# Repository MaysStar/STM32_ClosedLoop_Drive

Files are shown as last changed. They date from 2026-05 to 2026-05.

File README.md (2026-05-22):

Project Overview: Closed-Loop Drive System

### STM32_ClosedLoop_Drive video demonstration 

Watch video (https://www.youtube.com/watch?v=i_icI5O8THY)

*Click on the image above to go to watch the video on YouTube*

### STM32_ClosedLoop_Drive printed circuit board
Знімок екрана 2026-05-22 155104

Знімок екрана 2026-05-22 155144

Знімок екрана 2026-05-22 155350

This project is a multi-node closed-loop drive control system consisting of two main processing units: STM32F412RET and STM32F103 (Blue Pill).
1. Motion Control Node (STM32F412RET)

The core of the system, responsible for high-speed motor regulation and data management:

    Motor Control: Implements PID regulation via PWM, utilizing encoder feedback and sensor measurements for precise motion.

    Data Logging: Performs real-time logging of system parameters to an SD card (FATFS, .csv files) and via UART.

    Operating System: Runs on FreeRTOS to ensure deterministic multitasking.

    Diagnostics: Supports SEGGER debugging. All communication protocols are optimized using DMA and Interrupt (IT) functions within the OSAL layer.

2. User Interface Node (STM32F103)

A dedicated MCU for human-machine interaction:

    I/O Peripherals: Features an OLED display, physical buttons, and a potentiometer for manual speed control.

    Control: Acts as the primary input for setpoints and system monitoring.

3. Communication & Architecture

    Inter-node Communication: The MCUs communicate via a CAN bus using a custom command table where each command is assigned a specific priority.

    Software Design: The project follows a strict 3-level architecture:

        BSP (Board Support Package): Hardware abstraction and HAL-level drivers.

        OSAL (Operating System Abstraction Layer): Integration of FreeRTOS features, thread-safe DMA operations, and synchronization.

        APP (Application Layer): High-level logic for user applications and control algorithms.

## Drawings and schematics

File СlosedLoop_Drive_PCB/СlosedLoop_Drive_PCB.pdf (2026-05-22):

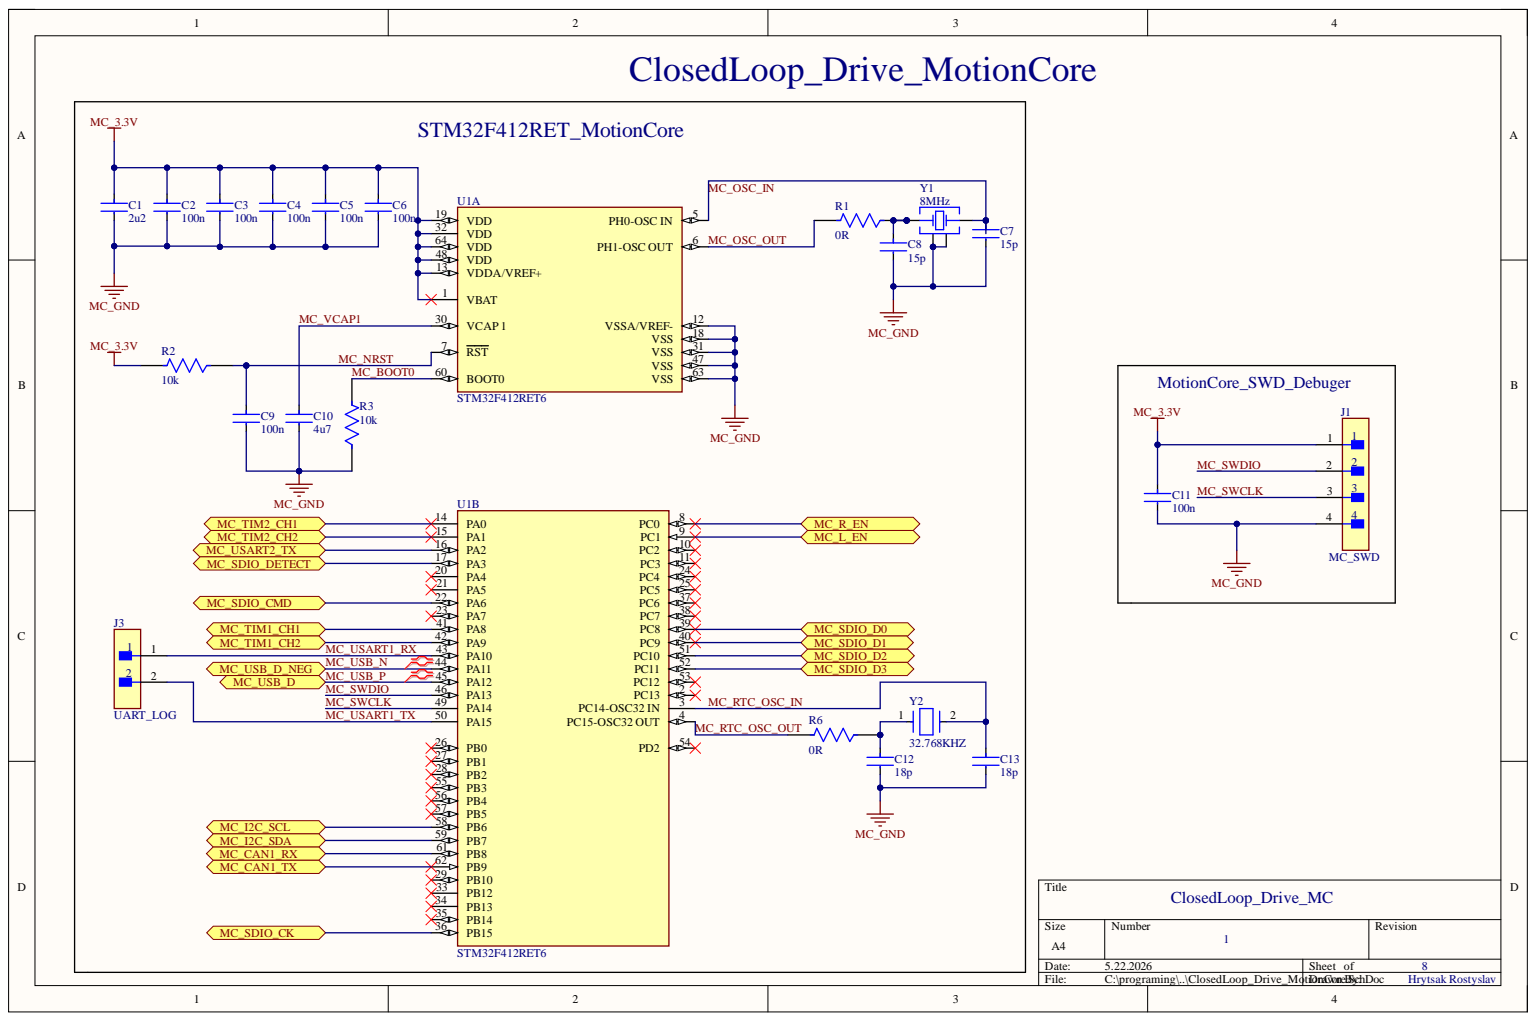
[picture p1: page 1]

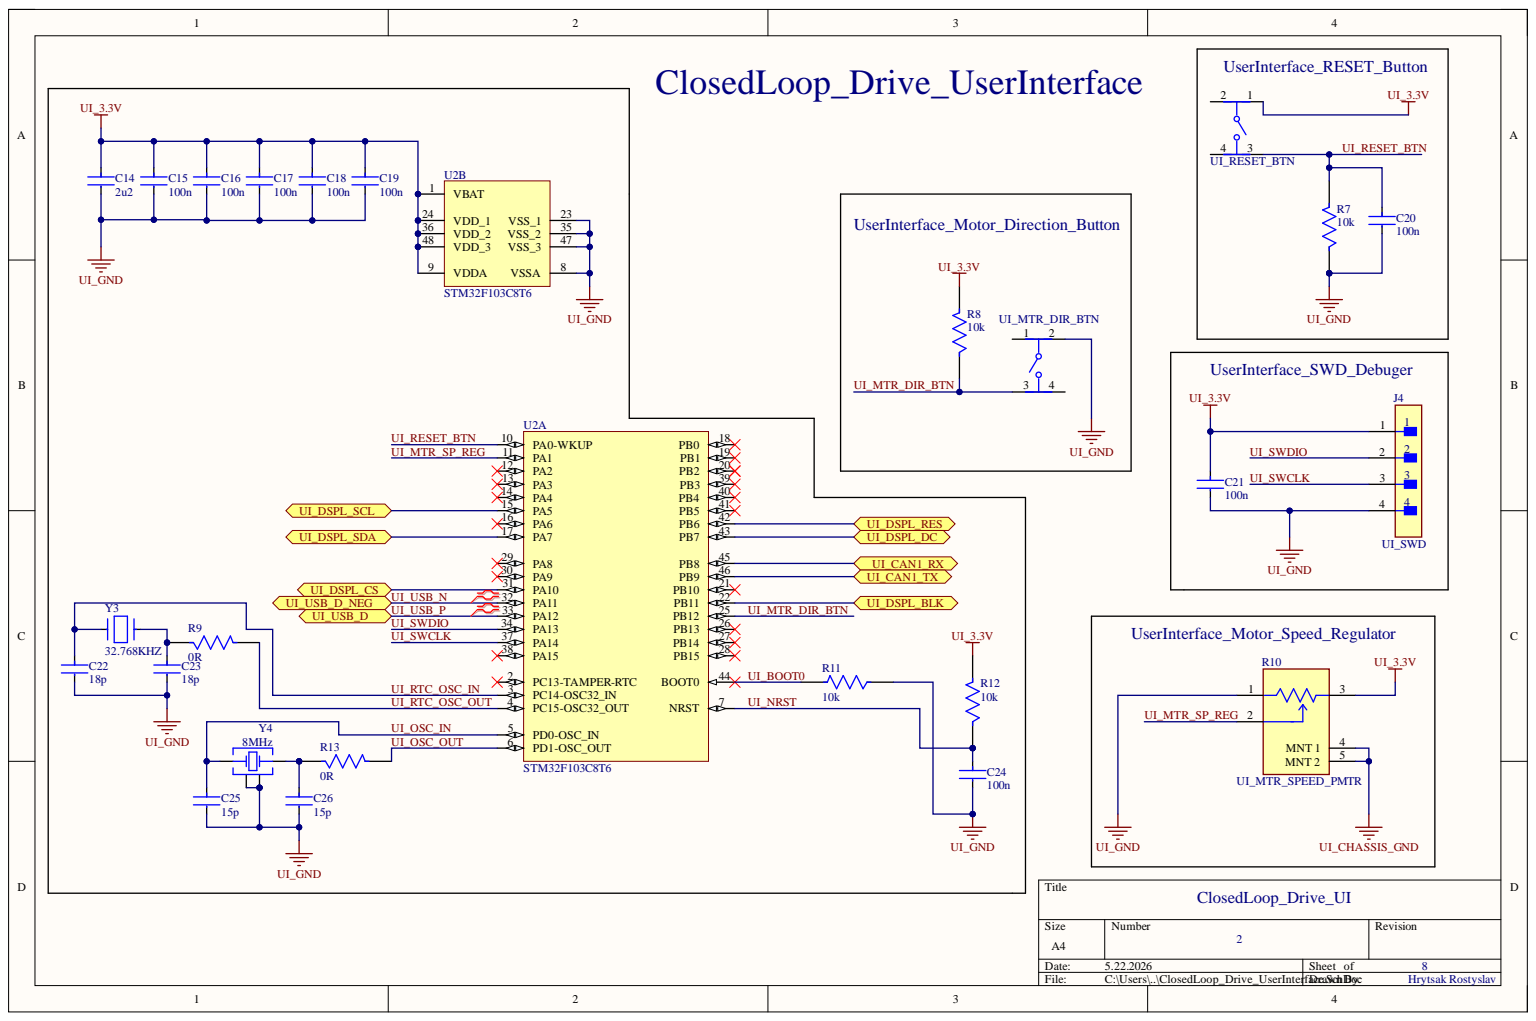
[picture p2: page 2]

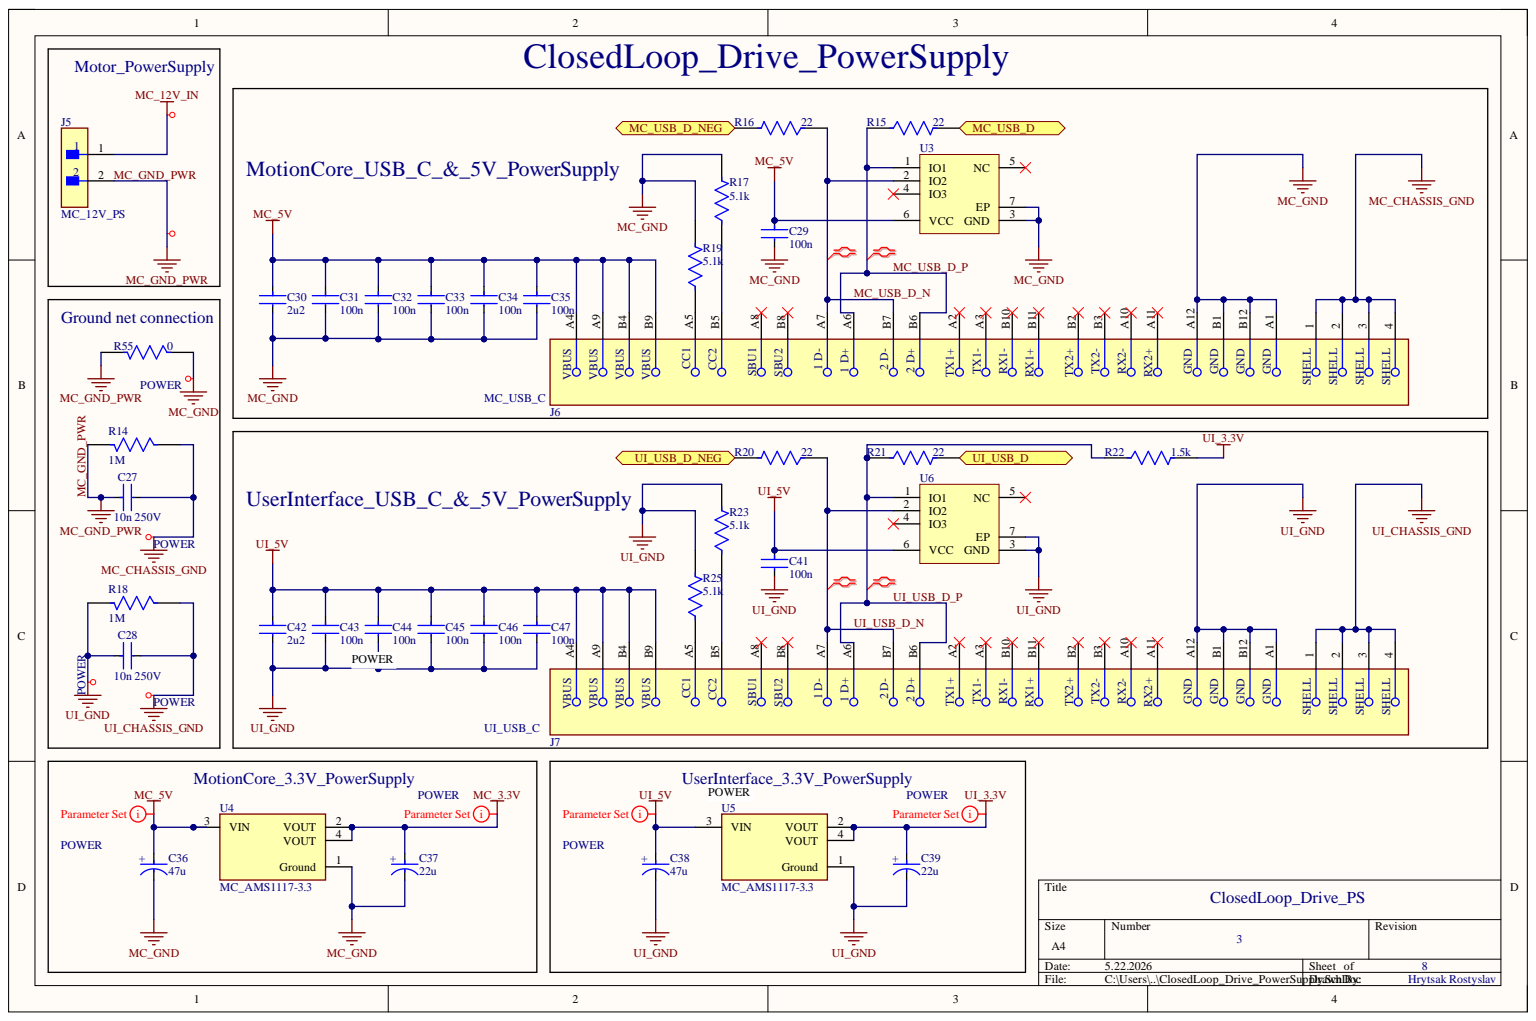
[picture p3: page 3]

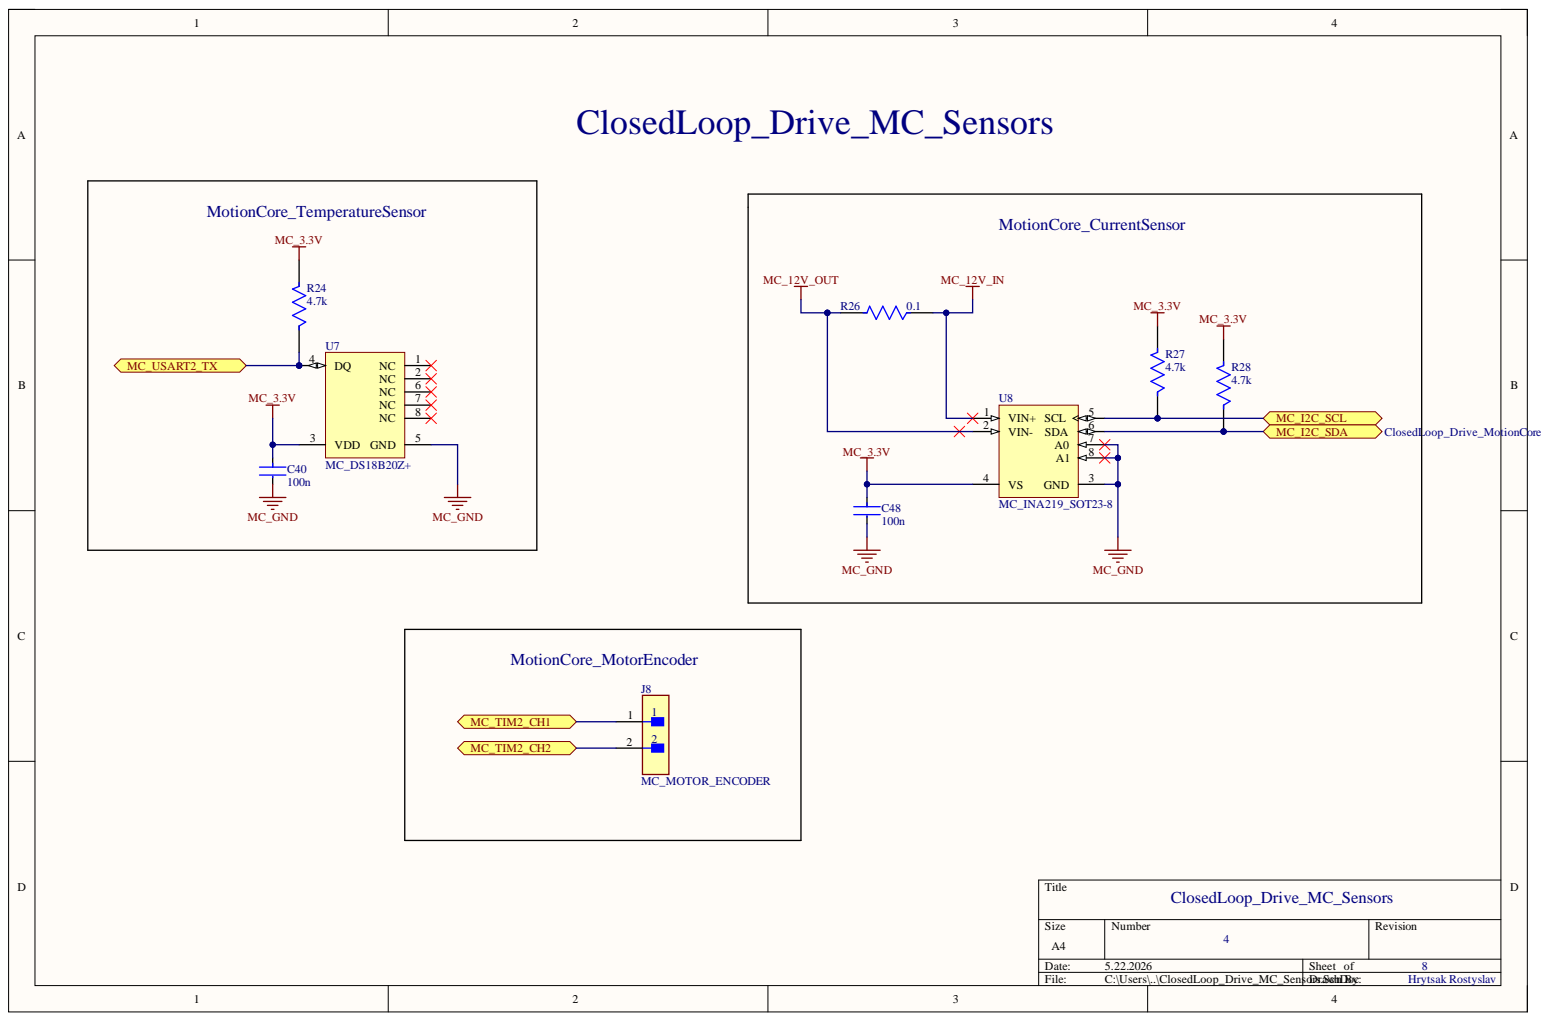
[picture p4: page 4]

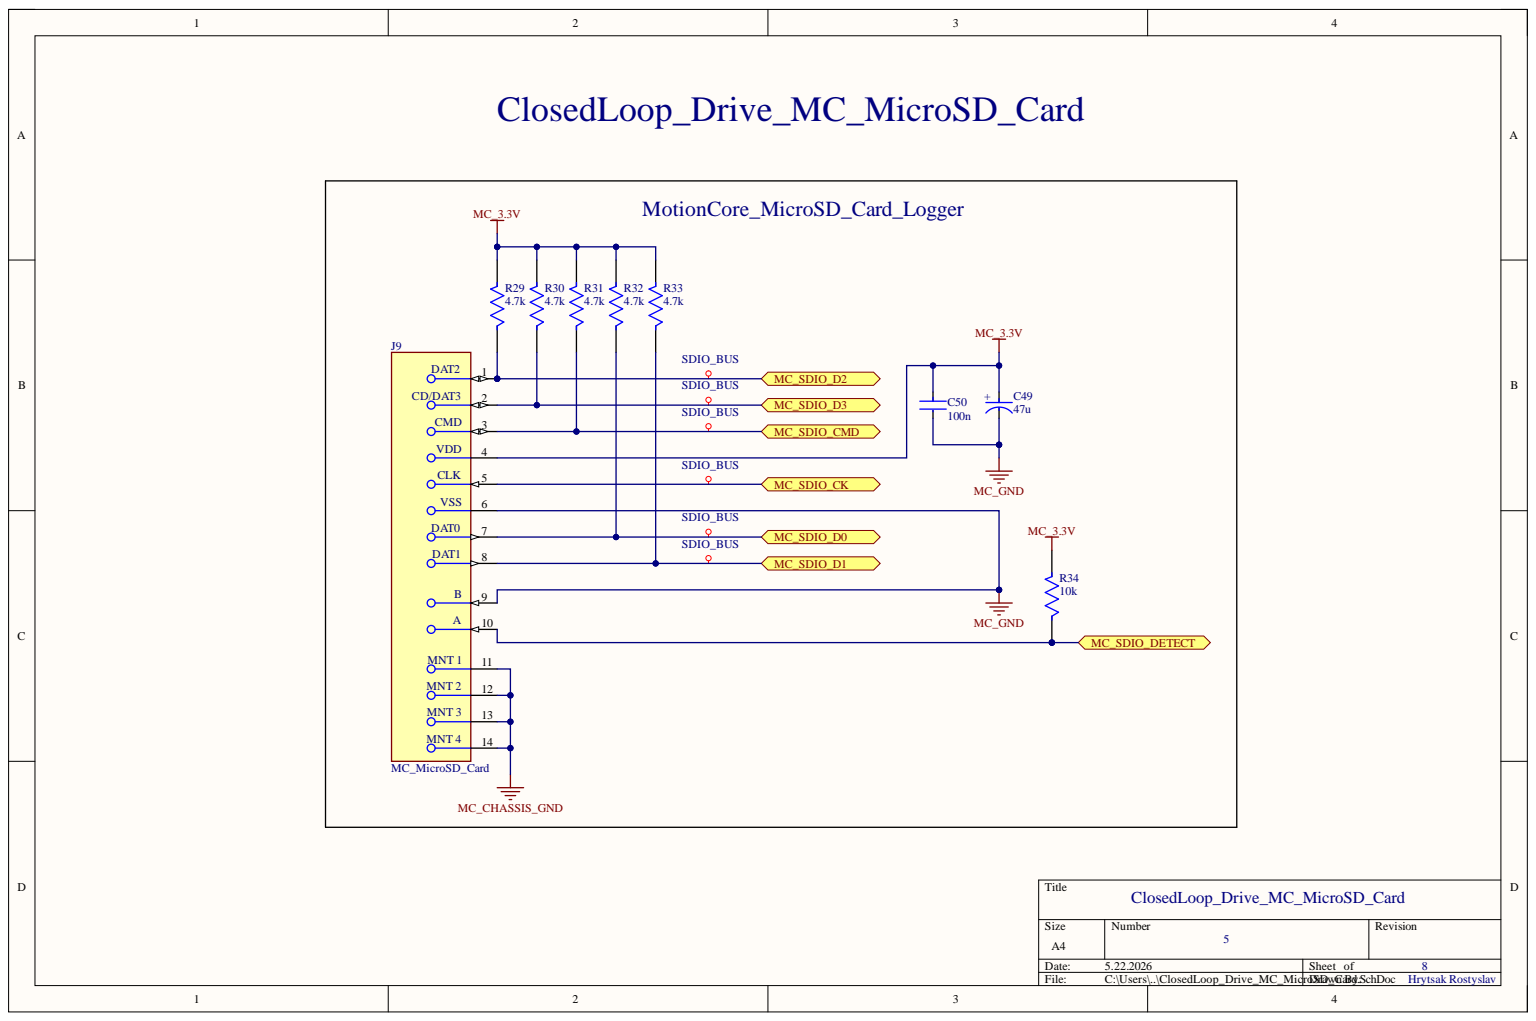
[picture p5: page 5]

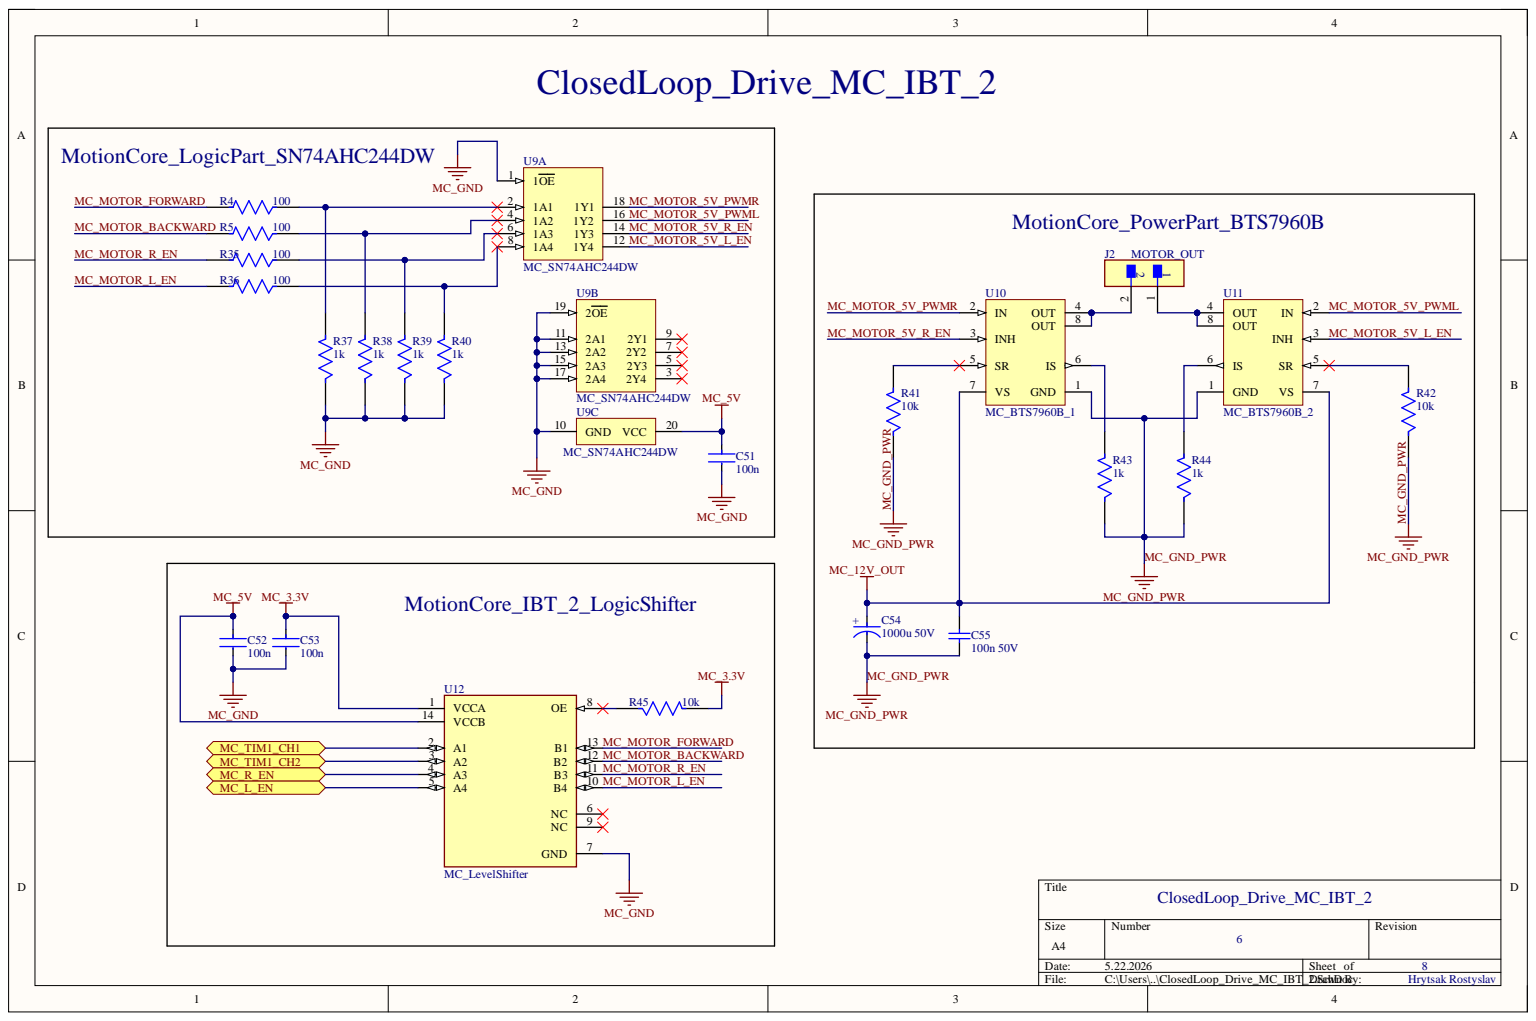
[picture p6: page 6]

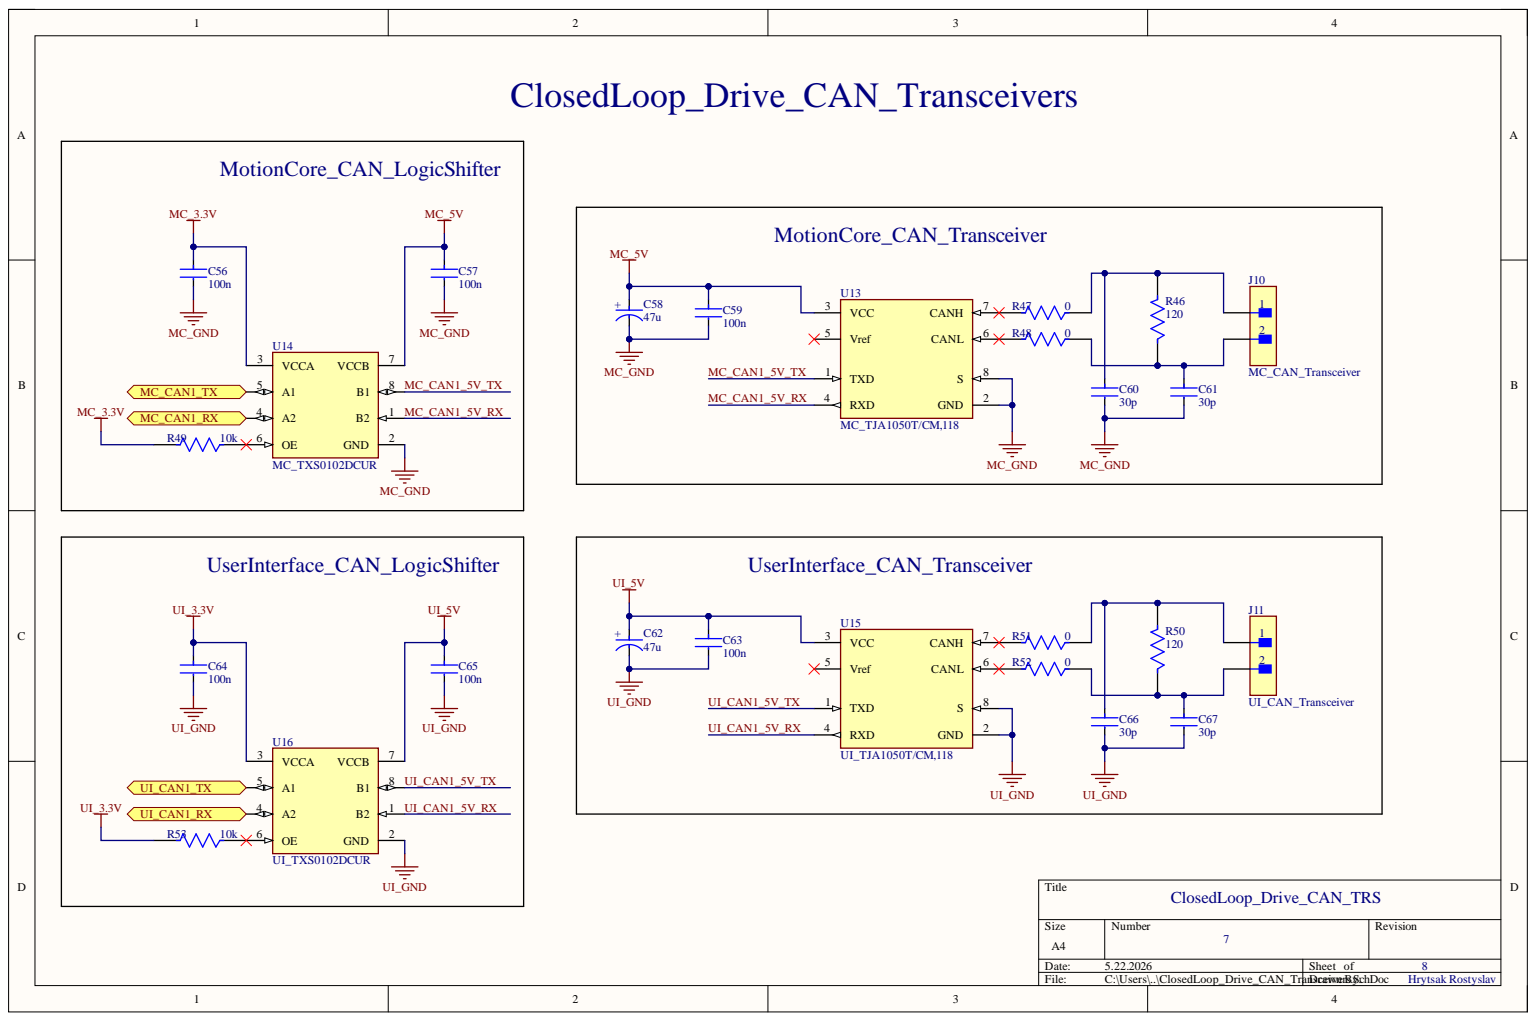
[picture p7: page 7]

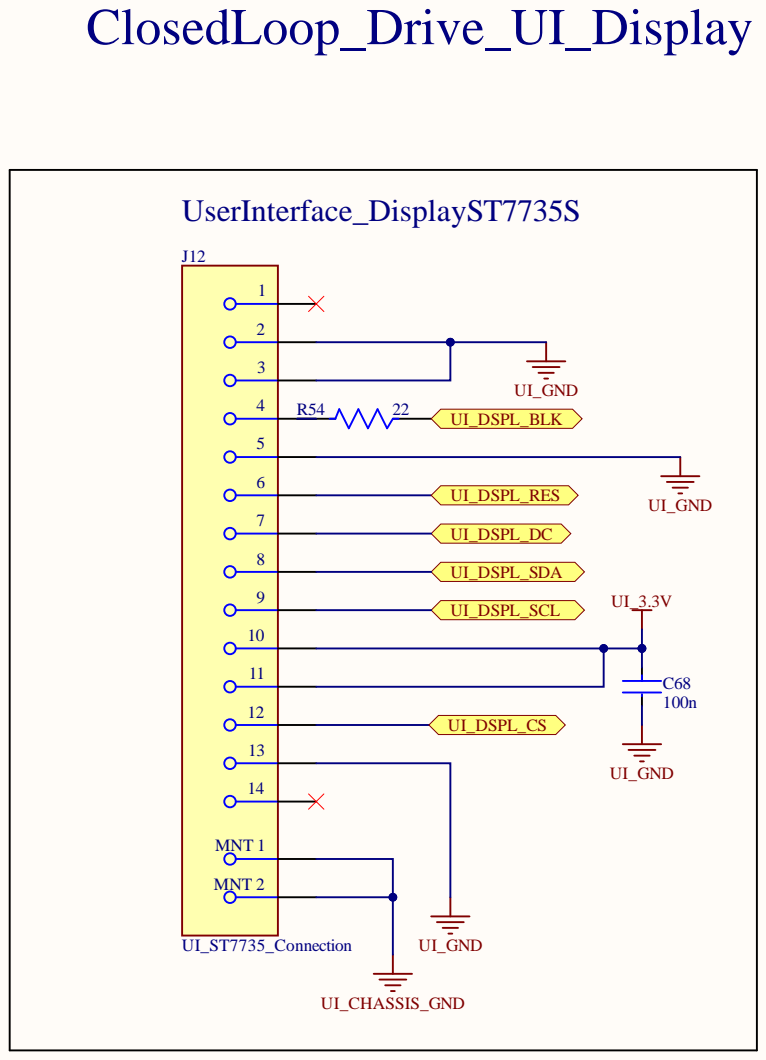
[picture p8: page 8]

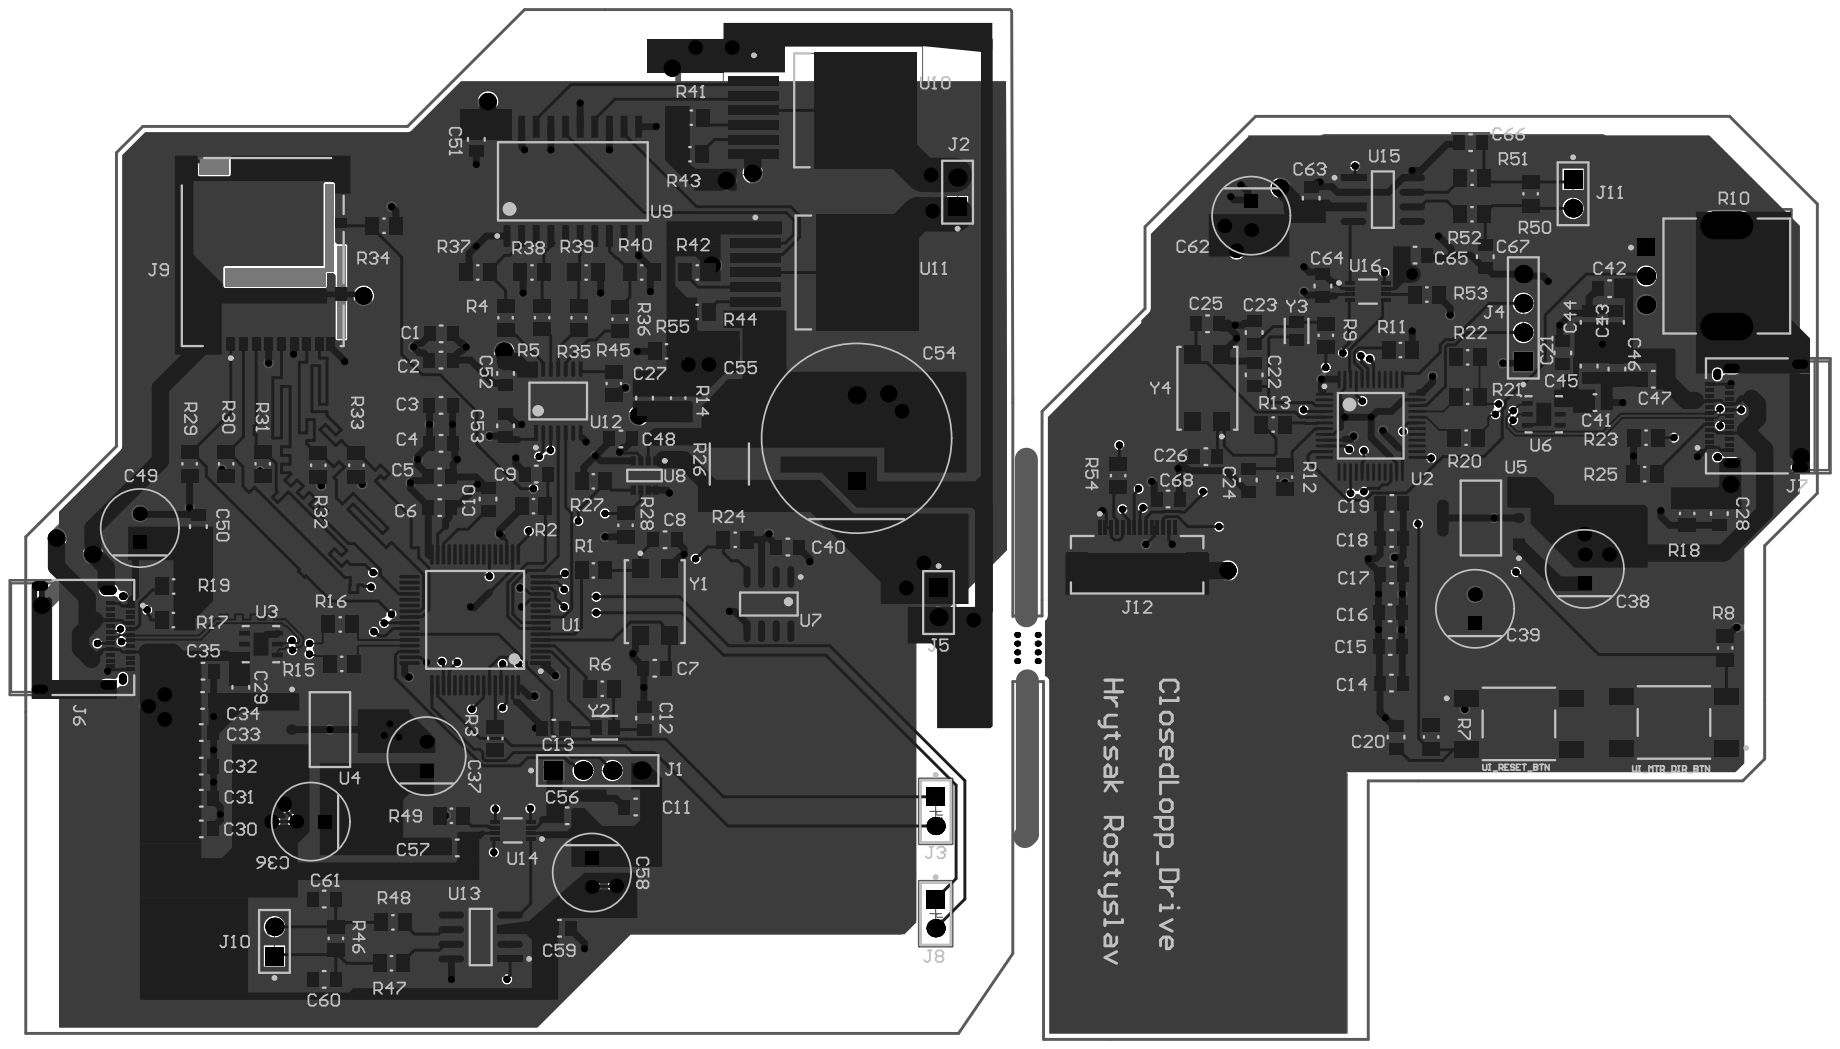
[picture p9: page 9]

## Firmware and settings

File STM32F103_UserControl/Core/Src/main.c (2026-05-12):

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
/* Includes ------------------------------------------------------------------*/
#include "main.h"

/* USER CODE BEGIN Includes */

#include "stdio.h"
#include "FreeRTOSConfig.h"
#include "FreeRTOS.h"
#include "task.h"

/* USER CODE END Includes */

ADC_HandleTypeDef hadc1;
DMA_HandleTypeDef hdma_adc1;

CAN_HandleTypeDef hcan;

IWDG_HandleTypeDef hiwdg;

RTC_HandleTypeDef hrtc;

SPI_HandleTypeDef hspi1;
DMA_HandleTypeDef hdma_spi1_tx;

void SystemClock_Config(void);
static void MX_GPIO_Init(void);
static void MX_DMA_Init(void);
static void MX_ADC1_Init(void);
static void MX_RTC_Init(void);
static void MX_SPI1_Init(void);
static void MX_IWDG_Init(void);
static void MX_CAN_Init(void);
/**
  * @brief  The application entry point.
  * @retval int
  */
int main(void)
{
  /* MCU Configuration--------------------------------------------------------*/

  /* Reset of all peripherals, Initializes the Flash interface and the Systick. */
  HAL_Init();

  /* USER CODE BEGIN Init */

  /* Enable DWT clock for proper work SEGGER SYSVIEW */
  CoreDebug->DEMCR |= CoreDebug_DEMCR_TRCENA_Msk;
  DWT->CYCCNT = 0;
  DWT->CTRL |= DWT_CTRL_CYCCNTENA_Msk;

  /* Set grouping priority manually for avoiding freeRTOS conflicts */
  NVIC_SetPriorityGrouping(0);

  /* USER CODE END Init */

  /* Configure the system clock */
  SystemClock_Config();

  /* Initialize all configured peripherals */
  MX_GPIO_Init();
  MX_DMA_Init();
  MX_ADC1_Init();
  MX_RTC_Init();
  MX_SPI1_Init();
//  MX_IWDG_Init();
  MX_CAN_Init();
  /* USER CODE BEGIN 2 */

  /* Set Hardware and start application layer */
  AppHardwareConfig_t app_hw =
  {
	.padc1 = &hadc1,
	.prtc = &hrtc,
	.piwdg = &hiwdg,
	.pspi1 = &hspi1,
	.pcan = &hcan,
  };
  APP_Main(&app_hw);

  /* USER CODE END 2 */

  /* Infinite loop */
  /* USER CODE BEGIN WHILE */
  while (1)
  {
    /* USER CODE END WHILE */

    /* USER CODE BEGIN 3 */
  }
  /* USER CODE END 3 */
}

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
/* USER CODE BEGIN 4 */

void vApplicationStackOverflowHook(void)
{
	while(1)
	{

	}
}

/* USER CODE END 4 */

/**
  * @brief  Period elapsed callback in non blocking mode
  * @note   This function is called  when TIM4 interrupt took place, inside
  * HAL_TIM_IRQHandler(). It makes a direct call to HAL_IncTick() to increment
  * a global variable "uwTick" used as application time base.
  * @param  htim : TIM handle
  * @retval None
  */
void HAL_TIM_PeriodElapsedCallback(TIM_HandleTypeDef *htim)
{
  if (htim->Instance == TIM4) {
    HAL_IncTick();
  }
}

/**
  * @brief  This function is executed in case of error occurrence.
  * @retval None
  */
void Error_Handler(void)
{
  /* USER CODE BEGIN Error_Handler_Debug */
  /* User can add his own implementation to report the HAL error return state */
  __disable_irq();
  while (1)
  {
  }
  /* USER CODE END Error_Handler_Debug */
}

#ifdef  USE_FULL_ASSERT
/**
  * @brief  Reports the name of the source file and the source line number
  *         where the assert_param error has occurred.
  * @param  file: pointer to the source file name
  * @param  line: assert_param error line source number
  * @retval None
  */
void assert_failed(uint8_t *file, uint32_t line)
{
  /* USER CODE BEGIN 6 */
  /* User can add his own implementation to report the file name and line number,
     ex: printf("Wrong parameters value: file %s on line %d\r\n", file, line) */
  /* USER CODE END 6 */
}
#endif /* USE_FULL_ASSERT */

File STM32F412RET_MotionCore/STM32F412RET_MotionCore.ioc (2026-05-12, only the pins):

Mcu.UserName=STM32F412RETx
PA0.Signal=S_TIM2_CH1_ETR
PA1.Signal=S_TIM2_CH2
PA10.Signal=USART1_RX
PA12.Signal=CAN1_TX
PA13.Signal=SYS_JTMS-SWDIO
PA14.Signal=SYS_JTCK-SWCLK
PA15.Signal=USART1_TX
PA2.Signal=USART2_TX
PA4.Signal=GPIO_Output
PA6.Signal=SDIO_CMD
PA7.Signal=GPIO_Output
PA8.Signal=S_TIM1_CH1
PA9.Signal=S_TIM1_CH2
PB15.Signal=SDIO_CK
PB6.Signal=I2C1_SCL
PB7.Signal=I2C1_SDA
PB8.Signal=CAN1_RX
PC0.Signal=GPIO_Output
PC1.Signal=GPIO_Output
PC10.Signal=SDIO_D2
PC11.Signal=SDIO_D3
PC8.Signal=SDIO_D0
PC9.Signal=SDIO_D1

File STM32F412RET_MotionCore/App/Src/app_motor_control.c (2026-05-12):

#include "app_motor_control.h"

/* private variables */
static volatile float actual_speed_percent = 0.0f;
static volatile float current_recover_pwm = 0.0f;

static float filtered_speed = 0.0f;

static PID_Controller_t PID_Controller = {0};

static TaskHandle_t motor_control_handle = NULL;
static void motor_control_task(void* pvParameters);

/* Initialize PID controller */
static void APP_MOTOR_CONTROL_PID_Controller_init(PID_Controller_t* PID_Controller)
{
	if(PID_Controller != NULL)
	{
		PID_Controller->Kp = 4.0f;
		PID_Controller->Ki = 1.5f;
		PID_Controller->Kd = 0.02f;

		PID_Controller->min_result = -100.0f;
		PID_Controller->max_result = 100.0f;

		PID_Controller->prev_error = 0.0f;
		PID_Controller->prev_measurement = 0.0f;

		PID_Controller->proportional = 0.0f;
		PID_Controller->integrator = 0.0f;
		PID_Controller->differentiator = 0.0f;

		/* 10 * dt, dt = 50ms tau = 500ms */
		PID_Controller->tau = 0.05f;

		PID_Controller->out = 0.0f;
	}
}
/* Fuction which control the speed of the motors speed, using Proportional Integration Differential
    u(t) = Kp * e(t) + Ki * iteg(e(t)dt) + Kd * de(t) / dt
*/
static float APP_MOTOR_CONTROL_PID_Update(PID_Controller_t* PID_controler, float measurement, float setpoint)
{
	/* Calculate error */
	float curr_error = setpoint - measurement;

	float dt_f = 0.05f;

	if(setpoint < 5.0)
	{
		return 0.0f;
	}

	/* Proportional */
	PID_controler->proportional = PID_controler->Kp * curr_error;

	/* Integrator Trapezoidal Rule */
	PID_controler->integrator = PID_controler->integrator + 0.5f * PID_controler->Ki * (PID_controler->prev_error + curr_error) * dt_f;

	/* Band-Limited Derivative */
	float diff_num = measurement - PID_controler->prev_measurement;
	PID_controler->differentiator =   (2.0f * PID_controler->Kd * diff_num
	                      - (2.0f * PID_controler->tau - dt_f) * PID_controler->differentiator)
	                      / (2.0f * PID_controler->tau + dt_f);
	/* Set prev measurement */
	PID_controler->prev_error = curr_error;
	PID_controler->prev_measurement = measurement;

	/* Calculate output */
	float out_raw = PID_controler->proportional + PID_controler->integrator - PID_controler->differentiator;

	/* Anti-windup back-calculation */
	float out_clamped = CLAMP(out_raw, PID_controler->min_result, PID_controler->max_result);
	PID_controler->integrator += (out_clamped - out_raw) * 0.1f;

	/* Assign final output */
	PID_controler->out = out_clamped;

	return PID_controler->out;
}

/* Initialize timer1 PWM and check errors */
void APP_MOTOR_CONTROL_init(TIM_HandleTypeDef* ptim1, TIM_HandleTypeDef* ptim2)
{
	APP_STATE_Update_Error_BeforeRTOSStart(ERR_TIM_PWM, ERR_ACTIVE);

	for(uint32_t i = 0; i < 3; ++i)
	{
		if(BSP_MOTOR_CONTROL_Init(ptim1, ptim2) == DRV_OK)
		{
			APP_STATE_Update_Error_BeforeRTOSStart(ERR_TIM_PWM, ERR_NOT_ACTIVE);
			break;
		}
	}

	/* Initialize PID control system */
	APP_MOTOR_CONTROL_PID_Controller_init(&PID_Controller);

	xTaskCreate(motor_control_task, "motor_control_task", 1024, NULL, 3, &motor_control_handle);
	configASSERT(motor_control_handle != NULL);
}

static float pid_pwm_percent;
static float encoder_delta;

/* Main task for Motor Control using State machine, PID and PWM */
static void motor_control_task(void* pvParameters)
{
	TickType_t xLastWakeTime;
	const TickType_t xFrequency = 50;

	APP_STATE_Set_Motor_TargetSpeed(10.0f);

	// Initialize the xLastWakeTime variable with the current time.
	xLastWakeTime = xTaskGetTickCount();

	while(1)
	{
		GlobalData_t global_state = APP_STATE_Get_Data();

		/* Start condition */
		if((global_state.motor_state == MOTOR_STOP) &&
		   (global_state.target_motor_speed != 0))
		{
			PID_Controller.integrator = 0.0f;
			PID_Controller.differentiator = 0.0f;
			PID_Controller.prev_error = 0.0f;
			PID_Controller.prev_measurement = actual_speed_percent;

			APP_STATE_Set_Motor_State(MOTOR_RUN);
		}

		encoder_delta = (float)OSAL_MOTOR_CONTROL_GetEncoderDifference();
		encoder_delta = (encoder_delta >= 0) ? encoder_delta : (-encoder_delta);

		/* Calculate speed in percent according to motor max speed */
		// encoder_dt = 50.
		actual_speed_percent = ((encoder_delta * 100) / APP_MOTOR_CONTROL_MAX_ENCODER_VAL_P50MS);

		APP_STATE_Set_Motor_ActualSpeed(actual_speed_percent);

		// low-pass filter
		filtered_speed = SPEED_FILTER_ALPHA * actual_speed_percent
		               + (1.0f - SPEED_FILTER_ALPHA) * filtered_speed;

		/* Target PWM value from PID control system */
		pid_pwm_percent = APP_MOTOR_CONTROL_PID_Update(&PID_Controller, filtered_speed, global_state.target_motor_speed);

		switch(global_state.motor_state)
		{
			case MOTOR_RUN:
			{
				if(OSAL_MOTOR_ChangePWM_State(pid_pwm_percent, global_state.motor_direction) != DRV_OK)
				{
					APP_STATE_Update_Error(ERR_TIM_PWM, ERR_ACTIVE);
				}
				else
				{
					APP_STATE_Update_Error(ERR_TIM_PWM, ERR_NOT_ACTIVE);
				}

				break;
			}
			case MOTOR_STOP:
			{
				actual_speed_percent = 0.0f;
				if(OSAL_MOTOR_ChangePWM_State(actual_speed_percent, MOTOR_ORDINARY_STOP) != DRV_OK)
				{
					APP_STATE_Update_Error(ERR_TIM_PWM, ERR_ACTIVE);
				}
				else
				{
					APP_STATE_Update_Error(ERR_TIM_PWM, ERR_NOT_ACTIVE);
				}
				break;
			}
			case MOTOR_RECOVER:
			{
				/* Increase value step by step */
				current_recover_pwm += 5.0f;

				if(current_recover_pwm >= pid_pwm_percent)
				{
					/* acceleration is finish */
					current_recover_pwm = pid_pwm_percent;
					APP_STATE_Set_Motor_State(MOTOR_RUN);
				}

				if(OSAL_MOTOR_ChangePWM_State(current_recover_pwm, global_state.motor_direction) != DRV_OK)
				{
					APP_STATE_Update_Error(ERR_TIM_PWM, ERR_ACTIVE);
				}
				else
				{
					APP_STATE_Update_Error(ERR_TIM_PWM, ERR_NOT_ACTIVE);
				}

				break;
			}
			case MOTOR_FAULT_STOP:
			{
				actual_speed_percent = 0.0f;
				if(OSAL_MOTOR_ChangePWM_State(actual_speed_percent, MOTOR_EMERGENCY_STOP) != DRV_OK)
				{
					APP_STATE_Update_Error(ERR_TIM_PWM, ERR_ACTIVE);
				}
				else
				{
					APP_STATE_Update_Error(ERR_TIM_PWM, ERR_NOT_ACTIVE);
				}

				/* Start recover speed */
				current_recover_pwm = 0.0f;
				APP_STATE_Set_Motor_State(MOTOR_RECOVER);
				break;
			}
			default:
				break;
		}

		vTaskDelayUntil(&xLastWakeTime, pdMS_TO_TICKS(xFrequency));
	}
}

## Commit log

2026-03-22 first initial commit with motor control architecture
2026-03-29 Add SD card and UART logging using DMA, FatFs, and FreeRTOS
    * SDIO and FatFs was configured by manual SDIO 4-bit mode with DMA for Sd card logging and also some debug feaches like ITM, SWO, SWV was added
    * Developed SD DMA with RTOS implementation. Additionally, added a UART2 logger also with DMA and function pointer in the BSP to follow the architecture
    * Solved some bugs in diskio.c and added a mutex on the SDIO bus
    * Solved some architecture problems (added a new architecture layer called OSAL). Implemented a threadsafe function for UART DMA transmission. Also created a Mutex and improved the DMA callback for SDIO in diskio.c
    [STM32F4_MotionCore Debug.cfg]
2026-03-30 Implemented SEGGER SYSVIEW to visualize system execution. The traces can be generated using .SVdat files
2026-03-30 Developed better structure for SEGGER's files
    * Implemented SEGGER SYSVIEW to visualize system execution. The traces can be generated using .SVdat files
    * Developed better segger's files structure
2026-04-05 Temperature, current, power and voltage sensors implementation
    * Implemented BSP and OSAL layers for DS18B20 temperature sensor. This is demo version, so the implementation may change based on real hardware testing
    * Add project overview for Closed-Loop Drive System
    Added project overview and detailed descriptions of the closed-loop drive system components, including the Motion Control Node and User Interface Node.
    * Refactored application architecture and solved some previous issues
    * Implemented INA219 driver for current, power and voltage measurements. Also added OSAL layer functions for thread-safe use. All tests passed successfully
    [STM32F4_MotionCore.ioc, app_main.c, app_sensors.c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]
2026-04-06 Fault tolerance and independent watchdog
    * Developed a new software safety system with strict state validation fo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
    [STM32F4_MotionCore.ioc, app_main.c, app_sensors.c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]
2026-04-14 Developed RTC based on LSI. Refactor OSAL: fix timeout handling issues
    [STM32F4_MotionCore.ioc, app_housekeeping.c, app_main.c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]
2026-04-14 feat: Implement TIM1 PWM (BSP, OSAL, APP layers). WIP: initial safety and user motor control implementations
2026-04-14 refactor: improve BSP architecture layer
    [STM32F4_MotionCore Debug.cfg]
2026-04-14 fix: resolve compilation errors after master merge
    [app_motor_control.c, app_sensors.c, osal_freertos.c]
2026-04-21 User control
    * feat: implement user_control unit and multylayer architecture (BSP, OSAL, APP)
    * feat: implement user input, using ADC with DMA for motor control speed
    * feat: RTC and IWDG all layers implementation
    * feat: implement ST7735S display driver with SPI/DMA support. Add display BSP, OSAL and APP layers
    [STM32F103_UserControl.cfg]
2026-04-26 Mcu communication
    * feat: implement CAN bus communication infrastructure. Add (BSP, OSAL, APP) layers
    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
2026-04-29 feat: implement PID controller and encoder logic. Develop on three abstraction layer (BSP, OSAL, APP)
2026-04-29 feat: implement low power standby mode via PA0 for voltage and current safe
2026-04-29 feat: fix some wrong define and logic issue in app_housekeeping
    [app_housekeeping.c]
2026-05-12 fix: final hardware and software stability adjustments
    [STM32F412RET_MotionCore.cfg]
2026-05-22 feat(hw): develop schematic and PCB for whole project ClosedLoop_Drive, including MC and UI
    [ClosedLoop_Drive_CAN_Transceivers.SchDoc, ClosedLoop_Drive_MC_IBT_2.SchDoc, ClosedLoop_Drive_MC_MicroSD_Card.SchDoc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]
2026-05-22 Enhance README with STM32 PCB images and section
    Added images and section for STM32_ClosedLoop_Drive PCB.

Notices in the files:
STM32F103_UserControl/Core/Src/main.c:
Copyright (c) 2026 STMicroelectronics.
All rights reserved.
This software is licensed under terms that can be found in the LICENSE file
